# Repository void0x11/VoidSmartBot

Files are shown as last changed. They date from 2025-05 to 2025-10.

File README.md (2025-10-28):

# 📦 VoidSmartBot Core V1.1

> A professionally engineered 4-layer PCB for mobile robotics and embedded systems.

---

## 🔧 Overview

**SmartBot Core V1.1** is a custom-designed control board tailored for mobile robotics platforms.  
Built on a 4-layer FR4 stack, it combines reliable power management, motor control, encoder support, and clean communication — all in a compact, Arduino Mega-compatible footprint.

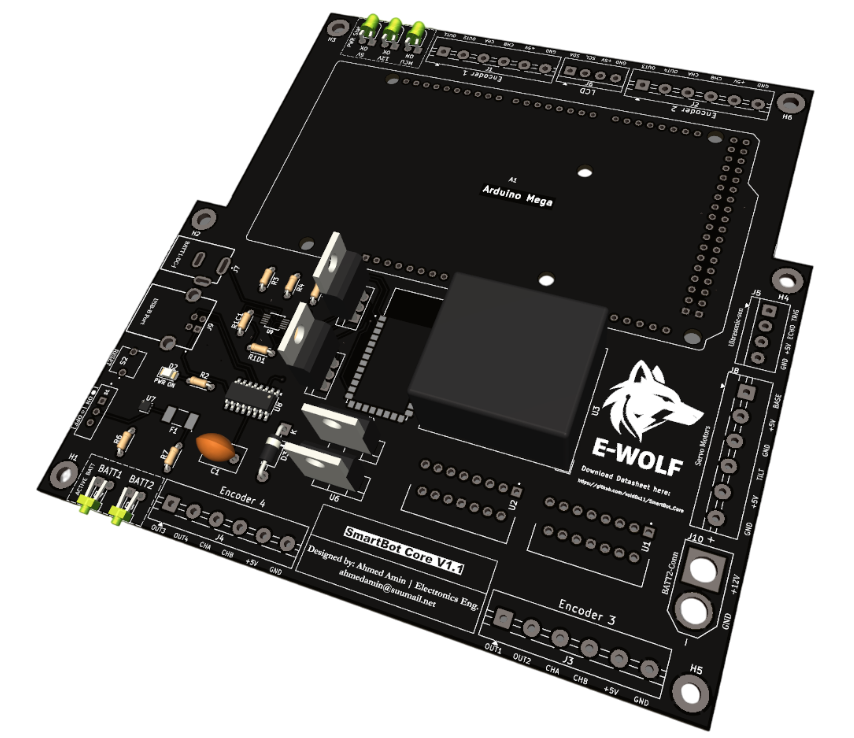
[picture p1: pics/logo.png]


---

## 🧠 Core Features

### 🔋 Power That Doesn’t Quit
- Dual battery input with seamless auto-switching (Power MUX)
- Over-voltage & over-current protection (TVS diode + SMD fuse)
- BAT1 / BAT2 source indicators via onboard LEDs

### ⚙️ Motion & I/O Control
- 4 DC motor outputs via integrated L298N (w/ flyback diodes)
- 4 quadrature encoder inputs (CHA/CHB)
- Support for ultrasonic sensors, servos, and I2C LCD modules

### 🛠️ Hardware Architecture
- ATmega2560 (Arduino Mega compatible)
- USB-B interface via CH340G (UART + programming)
- 54 digital I/O, 16 analog inputs, 14 PWM channels, 10-bit ADC
- 4-layer FR4 with internal GND & Power planes
- GND stitching vias for EMI noise reduction
- Clear silkscreen labeling & breakout headers
- Onboard diagnostic LEDs for 12V, 5V, MCU, and system power

---

## 📐 Board Dimensions

- 📏 Size: 130mm × 133mm  
- 🧩 Form Factor: Arduino Mega shield compatible

---

## 🖼️ Board Gallery

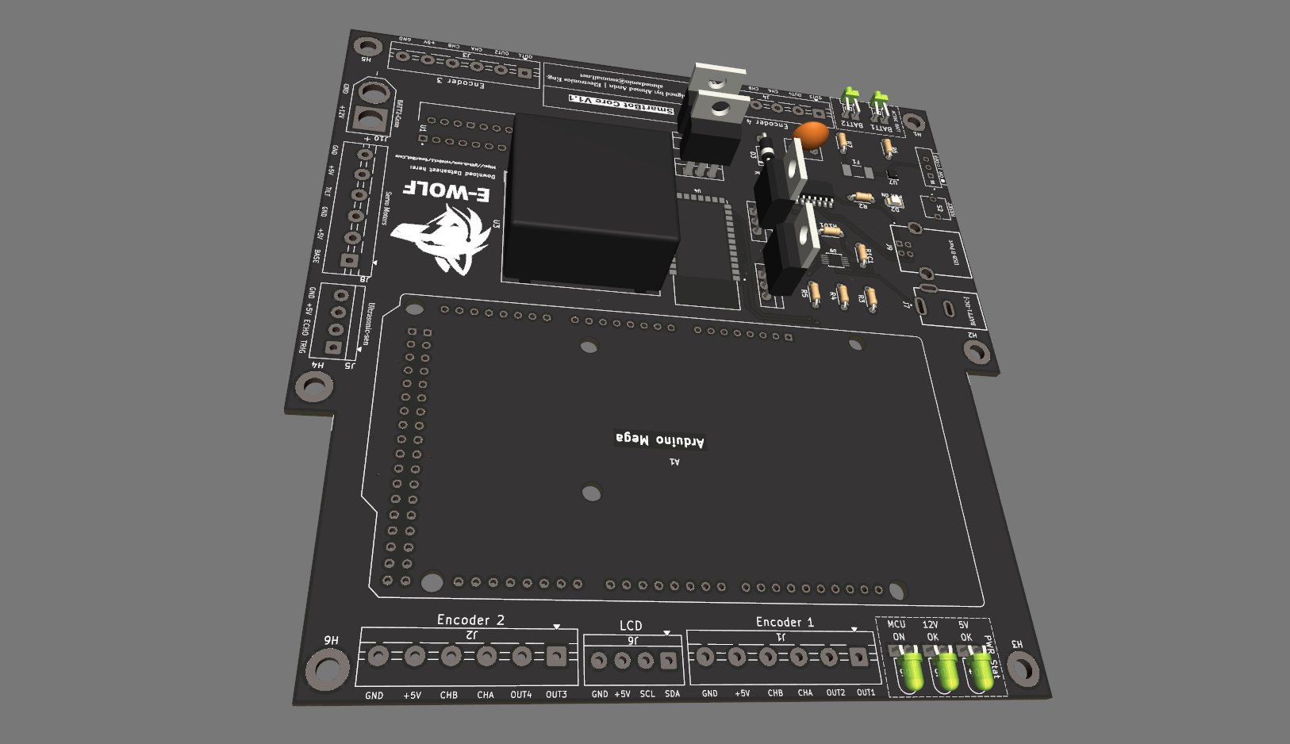
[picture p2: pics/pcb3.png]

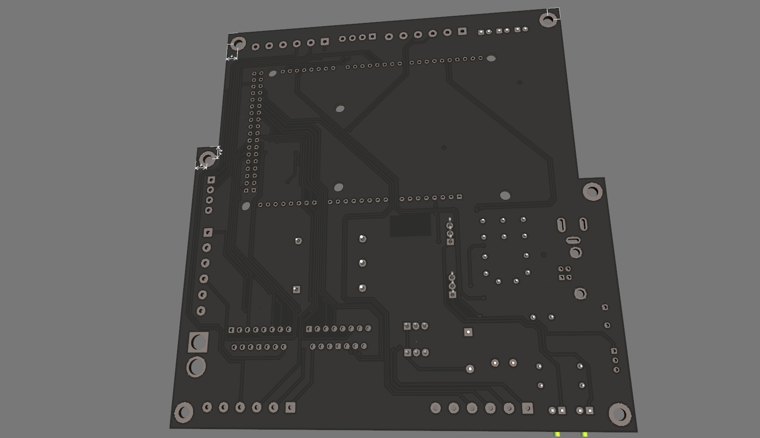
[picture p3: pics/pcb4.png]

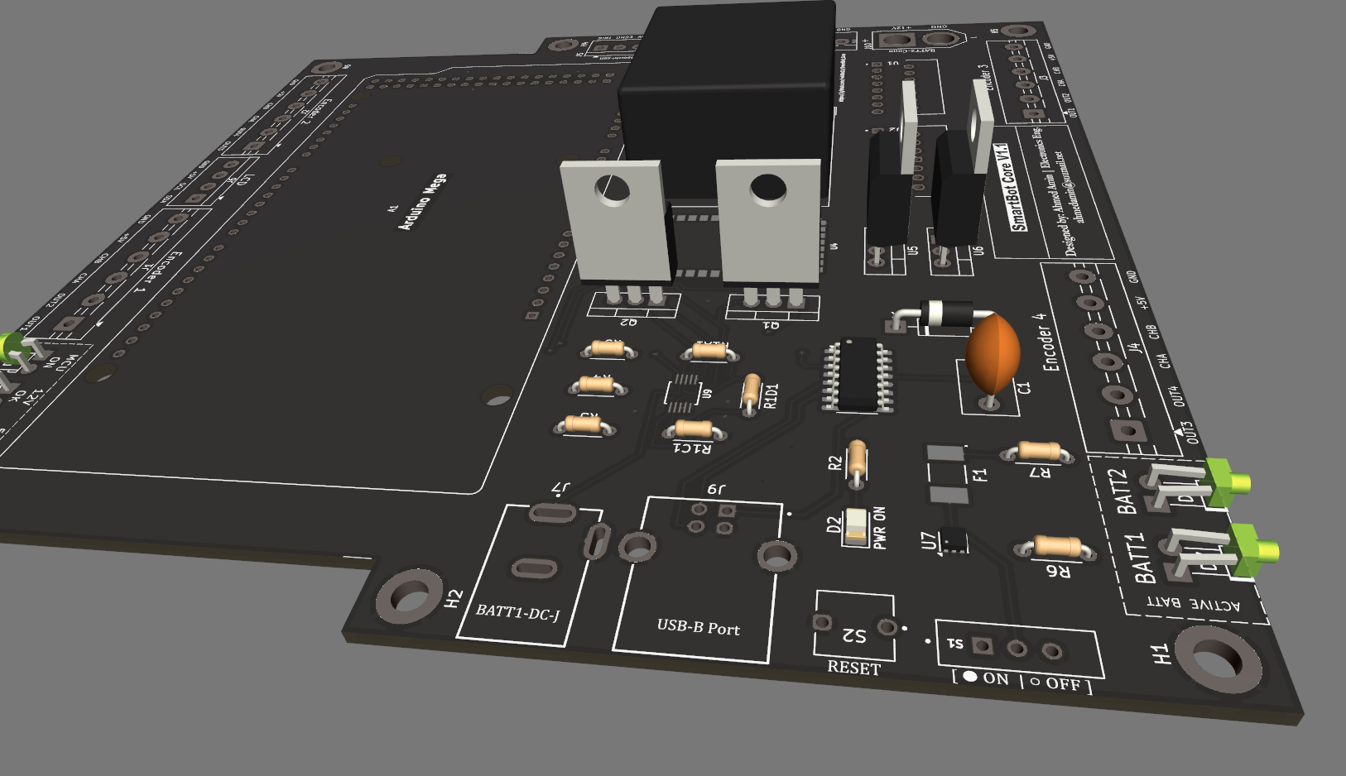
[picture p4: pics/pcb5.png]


---

## 🧱 Schematic & PCB Layer Stack
Schematic

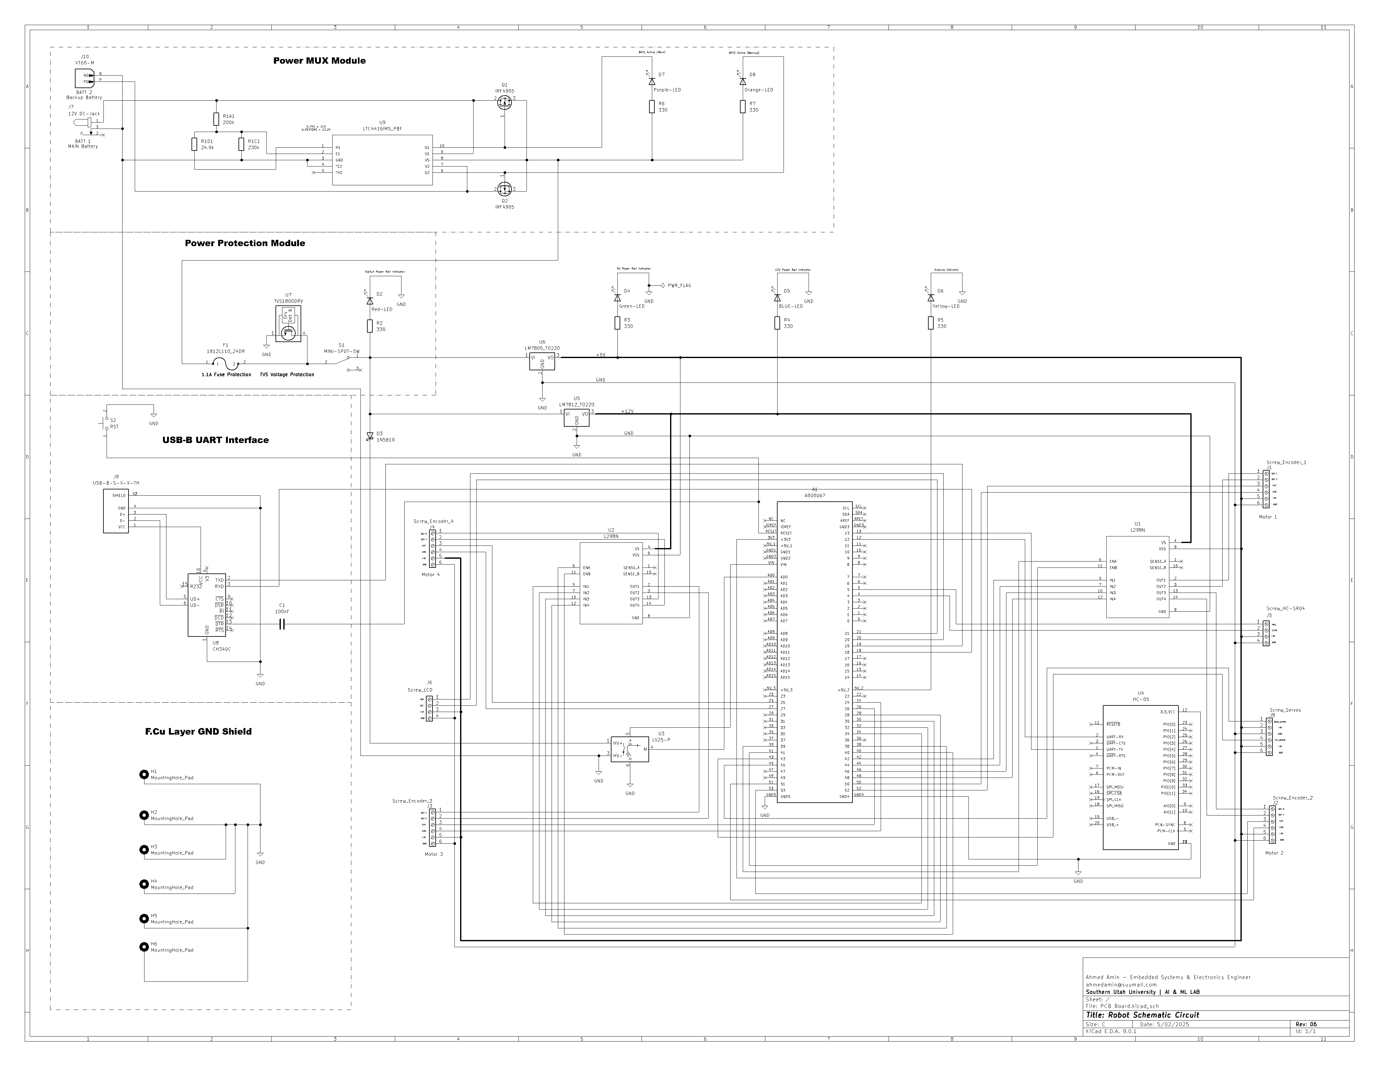
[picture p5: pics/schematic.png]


Layer 1 (Surface Mount)

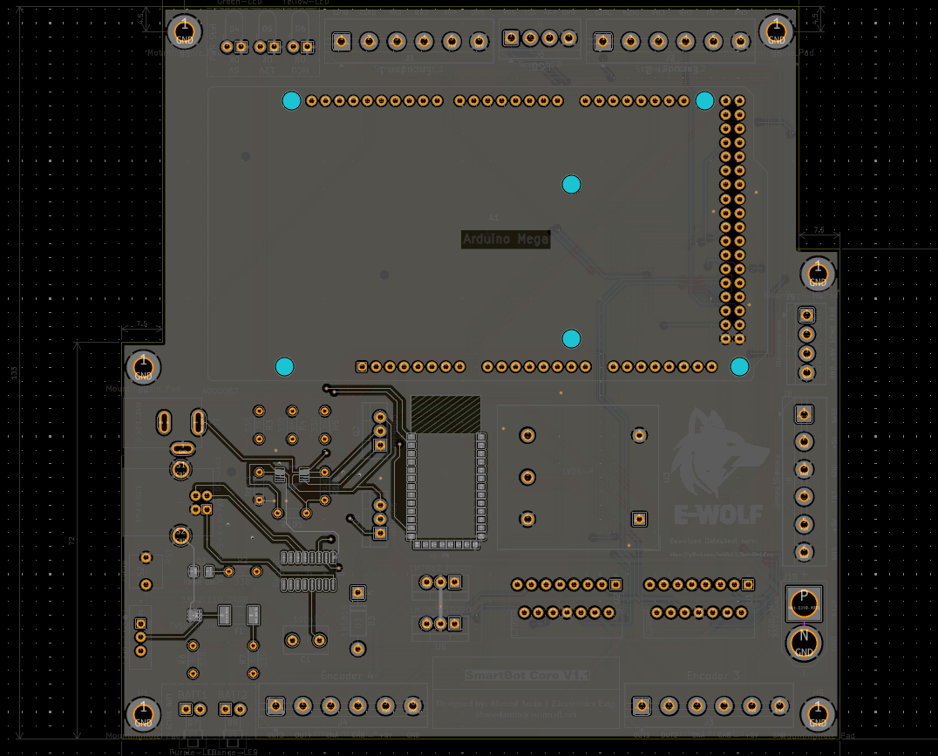
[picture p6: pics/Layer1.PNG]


Layer 2 (Light Signals, GND Refrence)

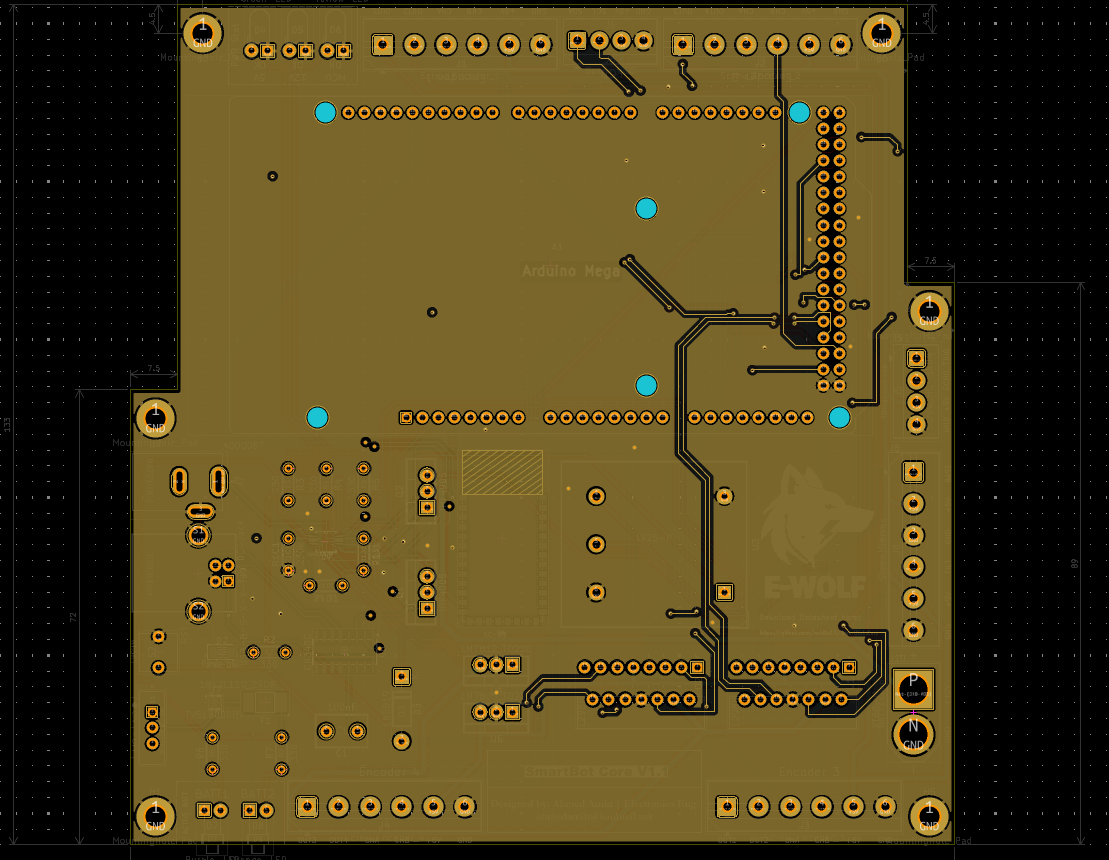
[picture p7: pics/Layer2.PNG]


Layer 3 (Power Plane)

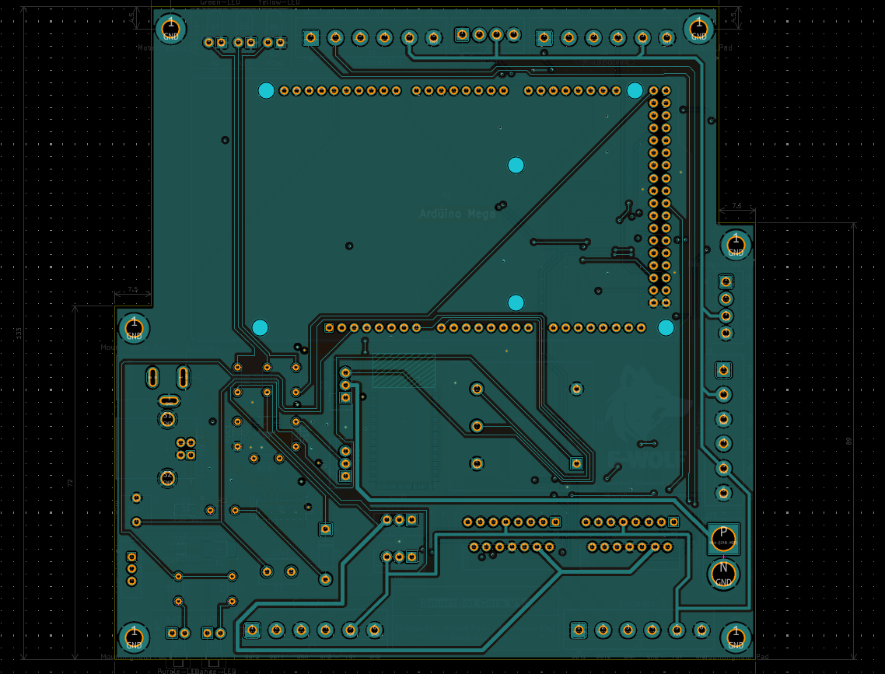
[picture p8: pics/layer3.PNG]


Layer 4 (Main Traces)

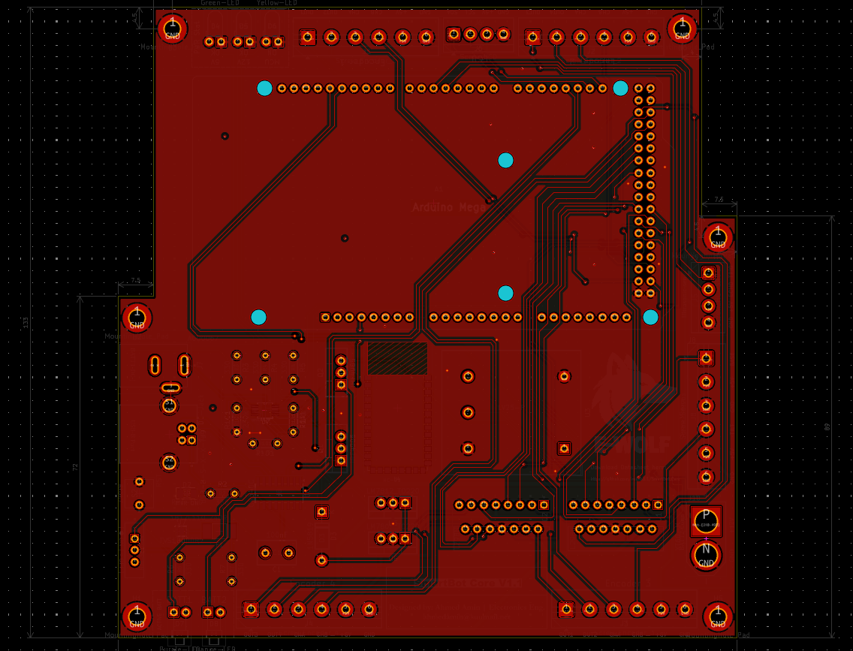
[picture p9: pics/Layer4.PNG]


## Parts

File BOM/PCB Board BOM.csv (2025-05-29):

Reference | Value | Footprint | Datasheet | Qty | DNP | Exclude from BOM | Exclude from Board
A1 | A000067 | MyParts:MODULE_A000067 |  | 1
C1 | 100nF | Capacitor_THT:C_Disc_D8.0mm_W5.0mm_P5.00mm | ~ | 1
D2 | Red-LED | LED_SMD:LED_1206_3216Metric | ~ | 1
D3 | 1N5819 | Diode_THT:D_DO-41_SOD81_P10.16mm_Horizontal | http://www.vishay.com/docs/88525/1n5817.pdf | 1
D4 | Green-LED | LED_THT:LED_D3.0mm_Horizontal_O1.27mm_Z2.0mm | ~ | 1
D5 | BLUE-LED | LED_THT:LED_D3.0mm_Horizontal_O1.27mm_Z2.0mm | ~ | 1
D6 | Yellow-LED | LED_THT:LED_D3.0mm_Horizontal_O1.27mm_Z2.0mm | ~ | 1
D7 | Purple-LED | LED_THT:LED_D1.8mm_W1.8mm_H2.4mm_Horizontal_O3.81mm_Z1.6mm | ~ | 1
D8 | Orange-LED | LED_THT:LED_D1.8mm_W1.8mm_H2.4mm_Horizontal_O3.81mm_Z1.6mm | ~ | 1
F1 | 1812L110_24DR | MyParts:FUSM4632X200N |  | 1
H1,H2,H3,H4,H5,H6 | MountingHole_Pad | MountingHole:MountingHole_3.2mm_M3_ISO7380_Pad | ~ | 6 |  | Excluded from BOM
J1 | Screw_Encoder_1 | TerminalBlock:TerminalBlock_MaiXu_MX126-5.0-06P_1x06_P5.00mm | ~ | 1
J2 | Screw_Encoder_2 | TerminalBlock:TerminalBlock_MaiXu_MX126-5.0-06P_1x06_P5.00mm | ~ | 1
J3 | Screw_Encoder_3 | TerminalBlock:TerminalBlock_MaiXu_MX126-5.0-06P_1x06_P5.00mm | ~ | 1
J4 | Screw_Encoder_4 | TerminalBlock:TerminalBlock_MaiXu_MX126-5.0-06P_1x06_P5.00mm | ~ | 1
J5 | Screw_HC-SR04 | TerminalBlock_4Ucon:TerminalBlock_4Ucon_1x04_P3.50mm_Horizontal | ~ | 1
J6 | Screw_LCD | TerminalBlock_4Ucon:TerminalBlock_4Ucon_1x04_P3.50mm_Horizontal | ~ | 1
J7 | 12V DC-Jack | MyParts:GCT_DCJ200-10-A-XX-K_REVA |  | 1
J8 | Screw_Servos | TerminalBlock:TerminalBlock_MaiXu_MX126-5.0-06P_1x06_P5.00mm | ~ | 1
J9 | USB-B-S-X-X-TH | MyParts:SAMTEC_USB-B-S-X-X-TH |  | 1
J10 | XT60-M | MyParts:AMASS_XT60-M |  | 1
Q1,Q2 | IRF4905 | Package_TO_SOT_THT:TO-220-3_Vertical | http://www.infineon.com/dgdl/irf4905.pdf?fileId=5546d462533600a4015355e32165197c | 2
R1A1 | 200k | Resistor_THT:R_Axial_DIN0204_L3.6mm_D1.6mm_P5.08mm_Horizontal | ~ | 1
R1C1 | 230k | Resistor_THT:R_Axial_DIN0204_L3.6mm_D1.6mm_P5.08mm_Horizontal | ~ | 1
R1D1 | 24.9k | Resistor_THT:R_Axial_DIN0204_L3.6mm_D1.6mm_P5.08mm_Horizontal | ~ | 1
R2,R3,R4,R5,R6,R7 | 330 | Resistor_THT:R_Axial_DIN0204_L3.6mm_D1.6mm_P5.08mm_Horizontal | ~ | 6
S1 | MINI-SPDT-SW | MyParts:SW_MINI-SPDT-SW |  | 1
S2 | RST | MyParts:SW_BUTT-2 |  | 1
U1,U2 | L298N | MyParts:TO127P2020X500X2100-15 |  | 2
U3 | LV25-P | Sensor_Voltage:LEM_LV25-P | https://www.lem.com/sites/default/files/products_datasheets/lv_25-p.pdf | 1
U4 | HC-05 | MyParts:XCVR_HC-05 |  | 1
U5 | LM7812_TO220 | Package_TO_SOT_THT:TO-220-3_Vertical | https://www.onsemi.cn/PowerSolutions/document/MC7800-D.PDF | 1
U6 | LM7805_TO220 | Package_TO_SOT_THT:TO-220-3_Vertical | https://www.onsemi.cn/PowerSolutions/document/MC7800-D.PDF | 1
U7 | TVS1800DRV | Package_SON:WSON-6-1EP_2x2mm_P0.65mm_EP1x1.6mm | http://www.ti.com/lit/ds/symlink/tvs1800.pdf | 1
U8 | CH340C | Package_SO:SOIC-16_3.9x9.9mm_P1.27mm | https://datasheet.lcsc.com/szlcsc/Jiangsu-Qin-Heng-CH340C_C84681.pdf | 1
U9 | LTC4416IMS_PBF | MyParts:MSOP-10_MS |  | 1

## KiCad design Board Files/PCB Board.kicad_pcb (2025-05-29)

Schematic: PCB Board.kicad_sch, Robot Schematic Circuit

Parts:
A1: A000067; MODULE_A000067; PARTREV 3
C1: 100nF; C_Disc_D8.0mm_W5.0mm_P5.00mm
D2: Red-LED; LED_1206_3216Metric
D3: 1N5819; D_DO-41_SOD81_P10.16mm_Horizontal
D4: Green-LED; LED_D3.0mm_Horizontal_O1.27mm_Z2.0mm
D5: BLUE-LED; LED_D3.0mm_Horizontal_O1.27mm_Z2.0mm
D6: Yellow-LED; LED_D3.0mm_Horizontal_O1.27mm_Z2.0mm
D7: Purple-LED; LED_D1.8mm_W1.8mm_H2.4mm_Horizontal_O3.81mm_Z1.6mm
D8: Orange-LED; LED_D1.8mm_W1.8mm_H2.4mm_Horizontal_O3.81mm_Z1.6mm
F1: 1812L110_24DR; FUSM4632X200N
H1, H2, H3, H4, H5, H6: MountingHole_Pad; MountingHole_3.2mm_M3_ISO7380_Pad
J1: Screw_Encoder_1; TerminalBlock_MaiXu_MX126-5.0-06P_1x06_P5.00mm
J2: Screw_Encoder_2; TerminalBlock_MaiXu_MX126-5.0-06P_1x06_P5.00mm
J3: Screw_Encoder_3; TerminalBlock_MaiXu_MX126-5.0-06P_1x06_P5.00mm
J4: Screw_Encoder_4; TerminalBlock_MaiXu_MX126-5.0-06P_1x06_P5.00mm
J5: Screw_HC-SR04; TerminalBlock_4Ucon_1x04_P3.50mm_Horizontal
J6: Screw_LCD; TerminalBlock_4Ucon_1x04_P3.50mm_Horizontal
J7: 12V DC-Jack; GCT_DCJ200-10-A-XX-K_REVA; PARTREV A
J8: Screw_Servos; TerminalBlock_MaiXu_MX126-5.0-06P_1x06_P5.00mm
J9: USB-B-S-X-X-TH; SAMTEC_USB-B-S-X-X-TH; PARTREV Q
J10: XT60-M; AMASS_XT60-M; PARTREV V1.2
Q1, Q2: IRF4905; TO-220-3_Vertical
R1A1: 200k; R_Axial_DIN0204_L3.6mm_D1.6mm_P5.08mm_Horizontal
R1C1: 230k; R_Axial_DIN0204_L3.6mm_D1.6mm_P5.08mm_Horizontal
R1D1: 24.9k; R_Axial_DIN0204_L3.6mm_D1.6mm_P5.08mm_Horizontal
R2, R3, R4, R5, R6, R7: 330; R_Axial_DIN0204_L3.6mm_D1.6mm_P5.08mm_Horizontal
S1: MINI-SPDT-SW; SW_MINI-SPDT-SW; PARTREV C
S2: RST; SW_BUTT-2; PARTREV N/A
U1, U2: L298N; TO127P2020X500X2100-15
U3: LV25-P; LEM_LV25-P
U4: HC-05; XCVR_HC-05; PARTREV v1.0
U5: LM7812_TO220; TO-220-3_Vertical
U6: LM7805_TO220; TO-220-3_Vertical
U7: TVS1800DRV; WSON-6-1EP_2x2mm_P0.65mm_EP1x1.6mm
U8: CH340C; SOIC-16_3.9x9.9mm_P1.27mm
U9: LTC4416IMS_PBF; MSOP-10_MS; MANUFACTURER_PART_NUMBER ltc4416ims1

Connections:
/+5V: J1.5, J2.5, J3.5, J4.5, J5.3, J6.3, J8.2, J8.5, R3.2, U1.9 (VSS), U2.9 (VSS), U6.3 (VO)
/+12V: R4.2, U1.4 (VS), U2.4 (VS), U5.3 (VO)
GND: A1.GND4, A1.GND5, D2.1 (K), D4.1 (K), D5.1 (K), D6.1 (K), H1.1, H2.1, H3.1, H4.1, H5.1, H6.1, J1.6, J2.6, J3.6, J4.6, J5.4, J6.4, J7.3, J8.3, J8.6, J9.4 (GND), J9.S1 (SHIELD), J9.S2 (SHIELD), J10.N (NEG), R1C1.1, S2.2, U1.8 (GND), U2.8 (GND), U3.3 (HV-), U3.6 (V-), U4.13 (GND), U4.21 (GND), U4.22 (GND), U5.2 (GND), U6.2 (GND), U7.1 (GND), U7.2 (GND), U7.3 (GND), U7.7 (GND), U8.1 (GND), U9.3 (GND), U9.4 (*E2)
unnamed: A1.3V3 (+3V3), U4.12 (3.3_VCC)
unnamed: A1.5V_2 (+5V_2), R5.2
unnamed: A1.RESET, C1.2, S2.1
unnamed: D2.2 (A), R2.1
unnamed: D3.2 (A), R2.2, S1.1, U5.1 (VI), U6.1 (VI)
unnamed: D3.1 (K), U3.1 (HV+)
unnamed: D4.2 (A), R3.1
unnamed: D5.2 (A), R4.1
unnamed: D6.2 (A), R5.1
unnamed: D7.2 (A), R6.1
unnamed: D7.1 (K), Q1.1 (G), U9.10 (G1)
unnamed: D8.2 (A), R7.1
unnamed: D8.1 (K), Q2.1 (G), U9.6 (G2)
unnamed: F1.2, S1.2, U7.4 (IN), U7.5 (IN), U7.6 (IN)
unnamed: J1.1, U1.2 (OUT1)
unnamed: J1.2, U1.3 (OUT2)
unnamed: A1.52, J1.3
unnamed: A1.50, J1.4
unnamed: J2.1, U1.13 (OUT3)
unnamed: J2.2, U1.14 (OUT4)
unnamed: A1.53, J2.3
unnamed: A1.51, J2.4
unnamed: J3.1, U2.2 (OUT1)
unnamed: J3.2, U2.3 (OUT2)
unnamed: A1.26, J3.3
unnamed: A1.24, J3.4
unnamed: J4.1, U2.13 (OUT3)
unnamed: J4.2, U2.14 (OUT4)
unnamed: A1.25, J4.3
unnamed: A1.27, J4.4
unnamed: A1.5, J5.1
unnamed: A1.4, J5.2
unnamed: A1.20, J6.1
unnamed: A1.21, J6.2
unnamed: A1.45, J8.1
unnamed: A1.43, J8.4
unnamed: J9.3 (D+), U8.5 (UD+)
unnamed: J9.2 (D-), U8.6 (UD-)
unnamed: J9.1 (VCC), U8.16 (VCC)
unnamed: J10.P (POS), Q2.2 (D), U9.7 (V2)
unnamed: J7.1, Q1.2 (D), R1A1.2, U9.9 (V1)
unnamed: F1.1, Q1.3 (S), Q2.3 (S), R6.2, R7.2, U9.8 (VS)
unnamed: A1.39, U1.6 (ENA)
unnamed: A1.41, U1.11 (ENB)
unnamed: A1.42, U1.5 (IN1)
unnamed: A1.44, U1.7 (IN2)
unnamed: A1.46, U1.10 (IN3)
unnamed: A1.48, U1.12 (IN4)
unnamed: A1.38, U2.6 (ENA)
unnamed: A1.40, U2.11 (ENB)
unnamed: A1.34, U2.5 (IN1)
unnamed: A1.32, U2.7 (IN2)
unnamed: A1.30, U2.10 (IN3)
unnamed: A1.28, U2.12 (IN4)
unnamed: A1.AD0, U3.4 (M)
unnamed: A1.VIN, U3.5 (V+)
unnamed: A1.12, U4.2 (UART-RX)
unnamed: A1.13, U4.1 (UART-TX)
unnamed: A1.18, U8.3 (RXD)
unnamed: A1.19, U8.2 (TXD)
unnamed: C1.1, U8.13 (~DTR)
unnamed: R1A1.1, R1C1.2, R1D1.2, U9.2 (E1)
unnamed: R1D1.1, U9.1 (H1)

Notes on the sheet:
SCL
+5V
5V Power Rail Indicator
GND
BATT 2 Backup Battery
OUT 4
BAT1 Active (Main)
CHB
F.Cu Layer GND Shield
Power Protection Module
ECHO
USB-B UART Interface
OUT 1
Motor 3
Switch Power Rail Indicator
OUT 2
Power MUX Module
CHA
OUT 3
12V Power Rail Indicator
BAT2 Active (Backup)
TILT_SERVO
SDA
V_FAIL = 11V V_RESTORE = 12.2V
TVS Voltage Protection
Arduino Indicator
1.1A Fuse Protection
Motor 1
BATT 1 MAIN Battery
Motor 2
Motor 4
TRIG
BASE_SERVO

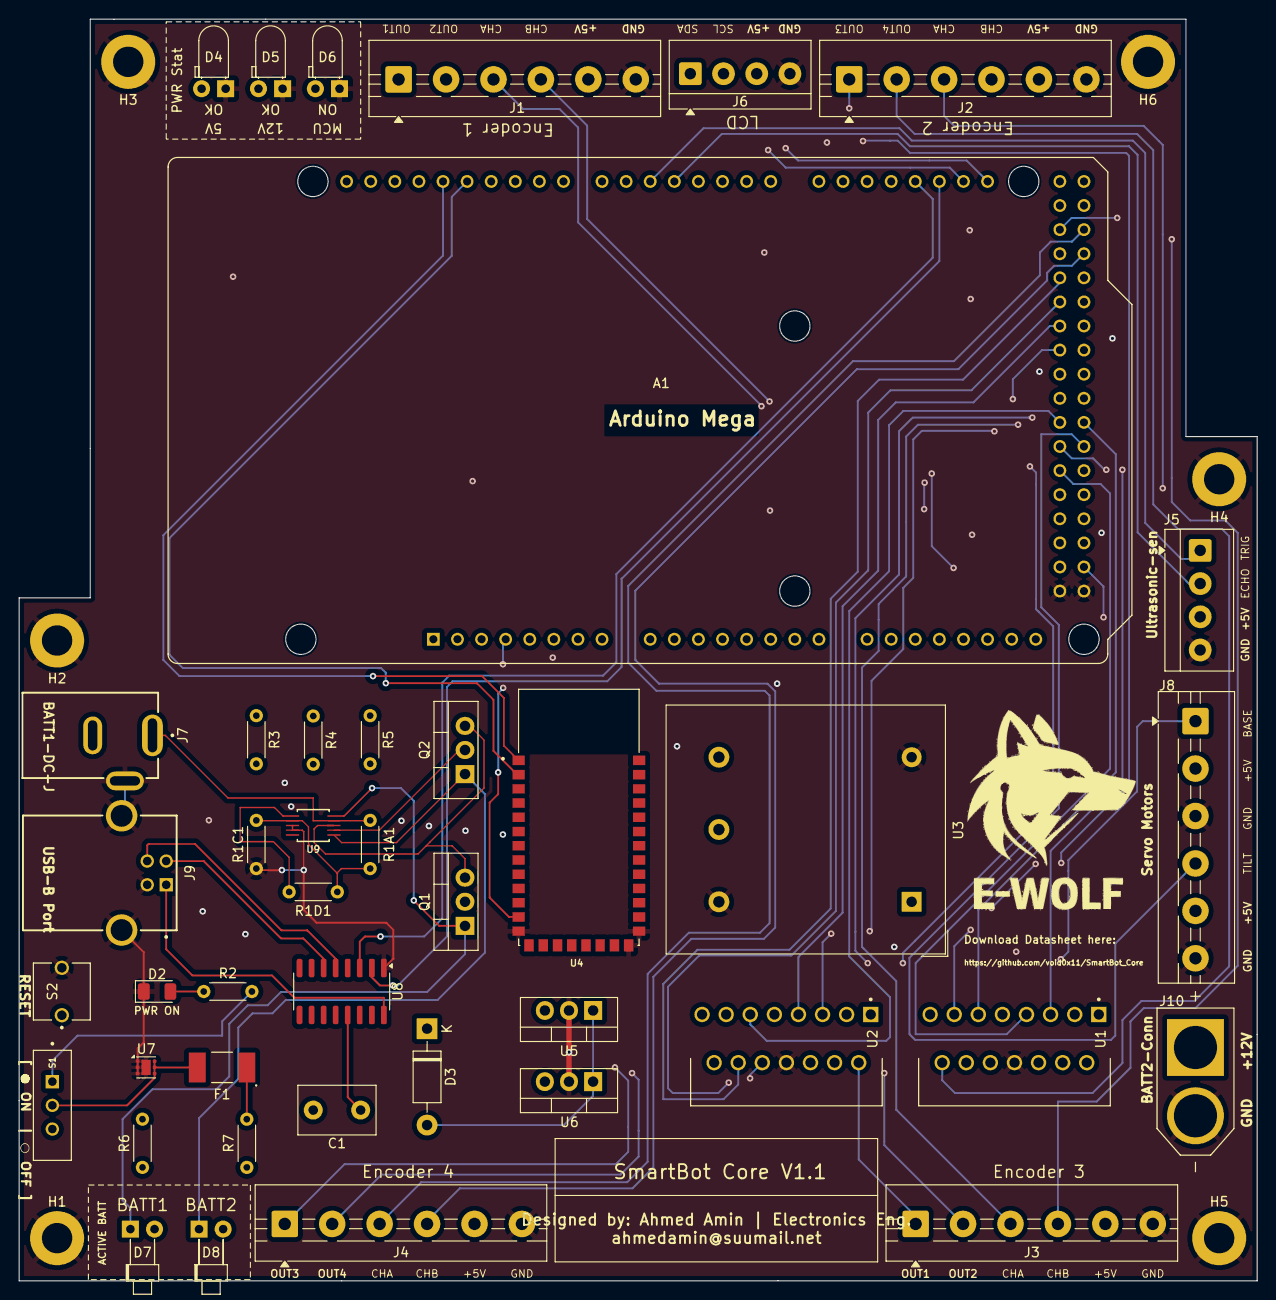
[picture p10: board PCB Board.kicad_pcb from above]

Board: 4 copper layers, 130.5 x 133.0 mm, 48 parts (0 on the bottom side), 66 nets.
